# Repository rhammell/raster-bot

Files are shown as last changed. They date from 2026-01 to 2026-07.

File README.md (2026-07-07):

# Raster Bot

Raster Bot

Raster Bot is a compact, two-wheeled differential-drive robot built around an
ESP32 and a capacitive touchscreen display. The project is fully open: it
includes the custom PCB, the 3D-printable mechanical design, the firmware
(packaged as an Arduino library), and the source graphics.

The firmware provides closed-loop motor control with quadrature encoders and
PID speed regulation, battery/charge monitoring, and a touchscreen UI — all
wrapped in a simple high-level API so sketches can drive the bot in a few lines.

## Build guide

A full step-by-step build tutorial — bill of materials, wiring, assembly, and
flashing — is published on Hackster.io:

**[Raster Bot build guide on Hackster.io](https://www.hackster.io/)** <!-- TODO: replace with the real tutorial URL -->

This README focuses on the contents of the repository and the firmware API;
see the Hackster guide if you want to build one from scratch.

## Repository structure

| Folder | Description |
| --- | --- |
| [`firmware/`](firmware/) | ESP32 firmware, packaged as the `Raster_Bot` Arduino library, plus example and tuning sketches. |
| [`hardware/`](hardware/) | KiCad project for the custom PCB (schematic, board layout, and footprint/symbol libraries). |
| [`mechanical/`](mechanical/) | FreeCAD model of the chassis and mechanical parts. |
| [`graphics/`](graphics/) | Logo artwork — SVG source and exported PNGs used for the board silkscreen and the boot splash screen. |

### `firmware/`

The firmware lives in `firmware/Raster_Bot/`, structured as an Arduino library:

| Path | Description |
| --- | --- |
| `src/Raster_Bot.h` / `.cpp` | Top-level `Raster_Bot` class that ties the subsystems together. |
| `src/definitions/` | Compile-time configuration: `pin_definitions.h` (wiring) and `robot_definitions.h` (tuning/behavior). |
| `src/display/` | `Raster_Display` — TFT, capacitive touch, and backlight control (plus the splash logo). |
| `src/battery/` | `Raster_Battery` — battery voltage and charger-status monitoring. |
| `src/drive/` | Differential drive stack: `Raster_Motor`, `Raster_Encoder`, `Raster_PID`, `Raster_Motor_Controller`, and `Raster_Drive`. |
| `examples/` | Standalone feature demos: `BatteryTest`, `GraphicsTest`, `TouchTest`. |
| `tuning/` | Calibration sketches, numbered in the order they should be run: `1_FeedforwardTuning`, `2_PIDTuning`, `3_WheelSyncTuning`, `4_DistanceTuning`. |
| `tests/` | Post-build verification sketches: `ForwardTest`, `DriftTest`. |
| `library.properties` | Arduino library metadata and dependencies. |

**Dependencies** (install via the Arduino Library Manager): Adafruit GFX
Library, Adafruit ILI9341, Adafruit FT6206 Library. Target architecture is
`esp32`.

### `hardware/`

KiCad design for the Raster Bot PCB. Open `hardware/Raster_Bot/Raster_Bot.kicad_pro`
in KiCad to view the schematic and board. Project-local footprint, symbol, and
3D-model libraries are under `hardware/Raster_Bot/libraries/`.

### `mechanical/`

FreeCAD source (`mechanical/src/Raster_Bot.FCStd`) for the robot's mechanical
design, parameterized for resizing.

### `graphics/`

- `src/raster_logo.svg` — master logo artwork.
- `export/raster_logo_silkscreen.png` — logo for the PCB silkscreen.
- `export/raster_logo_splash.png` — logo shown on the display at boot.

## Firmware API

Include the library and create a single `Raster_Bot` instance. It exposes three
subsystems as public members: `display`, `battery`, and `drive`.

```cpp
#include <Raster_Bot.h>

Raster_Bot bot;

void setup() {
    Serial.begin(115200);
    if (!bot.begin()) {
        Serial.println("Raster Bot init failed");
        while (1);
    }
    bot.drive.straight(10.0f);   // drive forward at 10 cm/s
}

void loop() {
    bot.drive.update();          // must be called frequently for PID control
}
```

### `Raster_Bot`

| Method | Description |
| --- | --- |
| `bool begin()` | Initializes the display, battery monitor, and drive subsystems. Returns `false` if any fail. |
| `display` | `Raster_Display` instance (see below). |
| `battery` | `Raster_Battery` instance (see below). |
| `drive` | `Raster_Drive` instance (see below). |

### `Raster_Display`

Extends Adafruit's `Adafruit_ILI9341`, so all standard Adafruit GFX drawing
calls are available in addition to:

| Method | Description |
| --- | --- |
| `bool begin()` | Initializes the TFT, touchscreen, and backlight. |
| `void showSplash()` | Plays the boot splash animation. |
| `void setBrightness(uint8_t brightness)` | Sets backlight brightness (0–255). |
| `bool touched()` | Returns `true` while the screen is being touched. |
| `TS_Point getTouchPoint()` | Returns the current touch point, mapped to the active screen rotation. |

### `Raster_Battery`

| Method | Description |
| --- | --- |
| `void begin()` | Initializes battery/charge-status monitoring. |
| `float voltage()` | Battery voltage in volts. |
| `bool charging()` | `true` while actively charging. |
| `bool chargerConnected()` | `true` when a charging source is plugged in. |

### `Raster_Drive`

Differential drive with per-wheel PID speed control. Call `update()` frequently
from `loop()` to run the control loop.

| Method | Description |
| --- | --- |
| `bool begin()` | Initializes the motor driver, both motor controllers, and encoders. |
| `void straight(float speed_cm_s)` | Drives both wheels at the given speed (negative = reverse). |
| `void stop()` | Stops both motors and goes idle. |
| `void update()` | Runs the drive control loop; call as often as possible. |
| `bool isMoving()` | `true` while a drive command is active. |
| `DriveTelemetry getTelemetry()` | Returns current motor telemetry. |
| `float getDistance()` | Returns cumulative straight-line distance, in cm, driven since power-on. |
| `void resetDistance()` | Resets the cumulative drive distance to zero. |

`DriveTelemetry` contains: `leftRPM`, `leftPWM`, `rightRPM`, `rightPWM`,
`leftCount`, and `rightCount` (wheel-output RPM and raw encoder counts).

## License

<!-- TODO: add a license (e.g. MIT for firmware, CERN-OHL or CC-BY-SA for hardware). -->

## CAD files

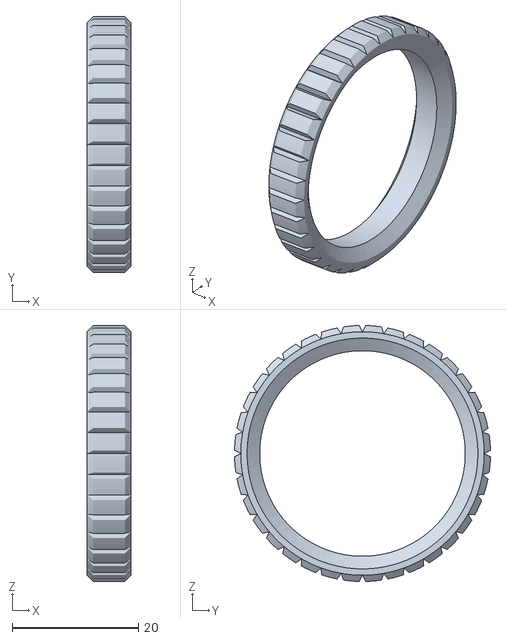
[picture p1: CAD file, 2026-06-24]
mechanical/export/Raster_Bot-Tire.stl
7.00 x 40.5 x 40.5

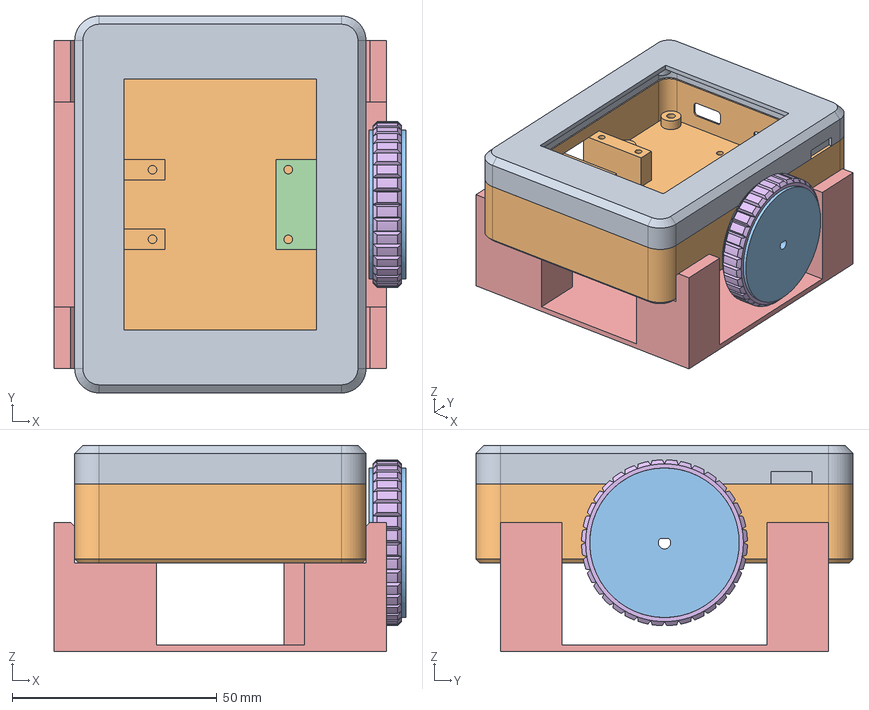
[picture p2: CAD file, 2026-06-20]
mechanical/src/Raster_Bot.FCStd
85.9 x 92.1 x 50.4 mm
Enclosure_Lid
Enclosure_Base
Wheel
Motor_Cover
Test_Stand
Tire

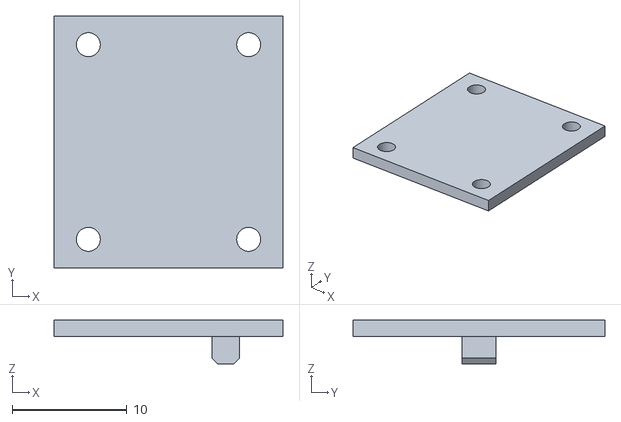
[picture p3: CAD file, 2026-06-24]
mechanical/export/Raster_Bot-Motor_Cover.stl
20.0 x 22.0 x 3.80

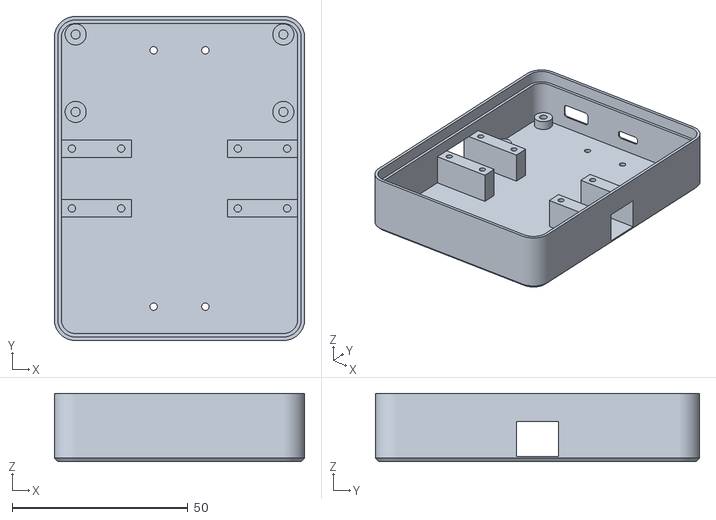
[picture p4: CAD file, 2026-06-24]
mechanical/export/Raster_Bot-Enclosure_Base.stl
71.2 x 92.0 x 19.4

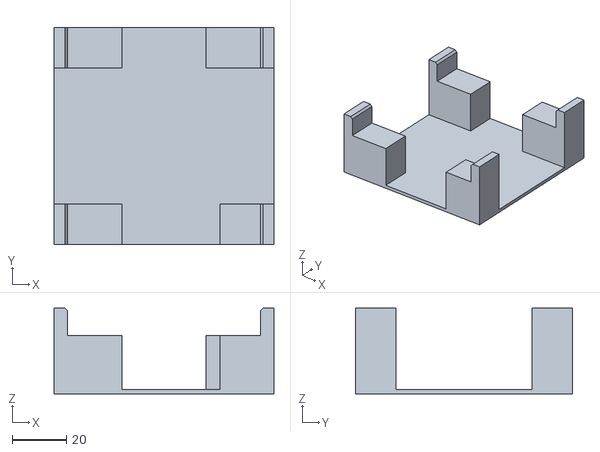
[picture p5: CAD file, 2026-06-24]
mechanical/export/Raster_Bot-Test_Stand.stl
81.2 x 80.0 x 31.6

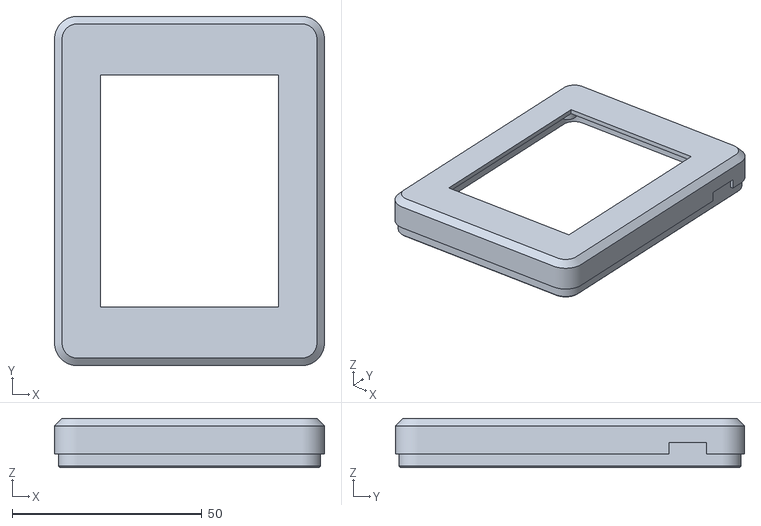
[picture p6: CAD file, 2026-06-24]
mechanical/export/Raster_Bot-Enclosure_Lid.stl
71.2 x 92.0 x 13.0

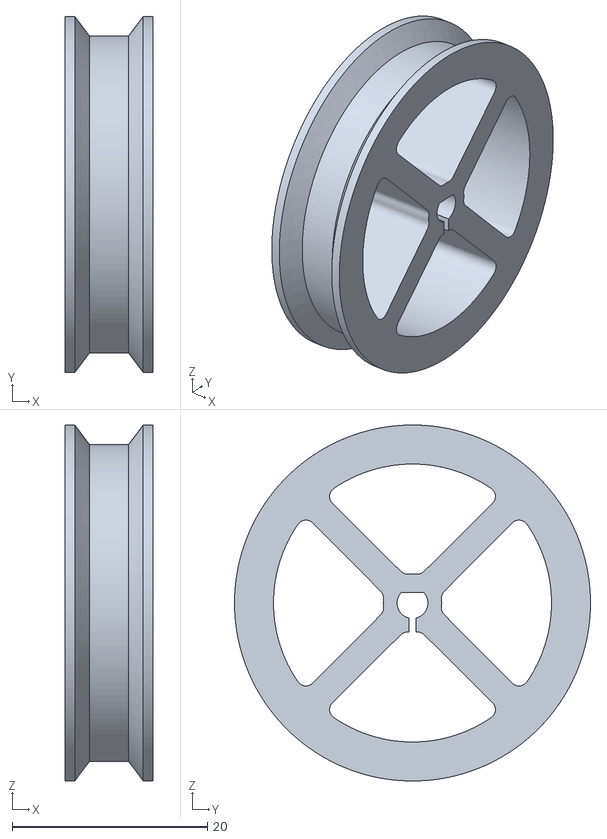
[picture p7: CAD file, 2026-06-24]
mechanical/export/Raster_Bot-Wheel.stl
9.00 x 36.5 x 36.5

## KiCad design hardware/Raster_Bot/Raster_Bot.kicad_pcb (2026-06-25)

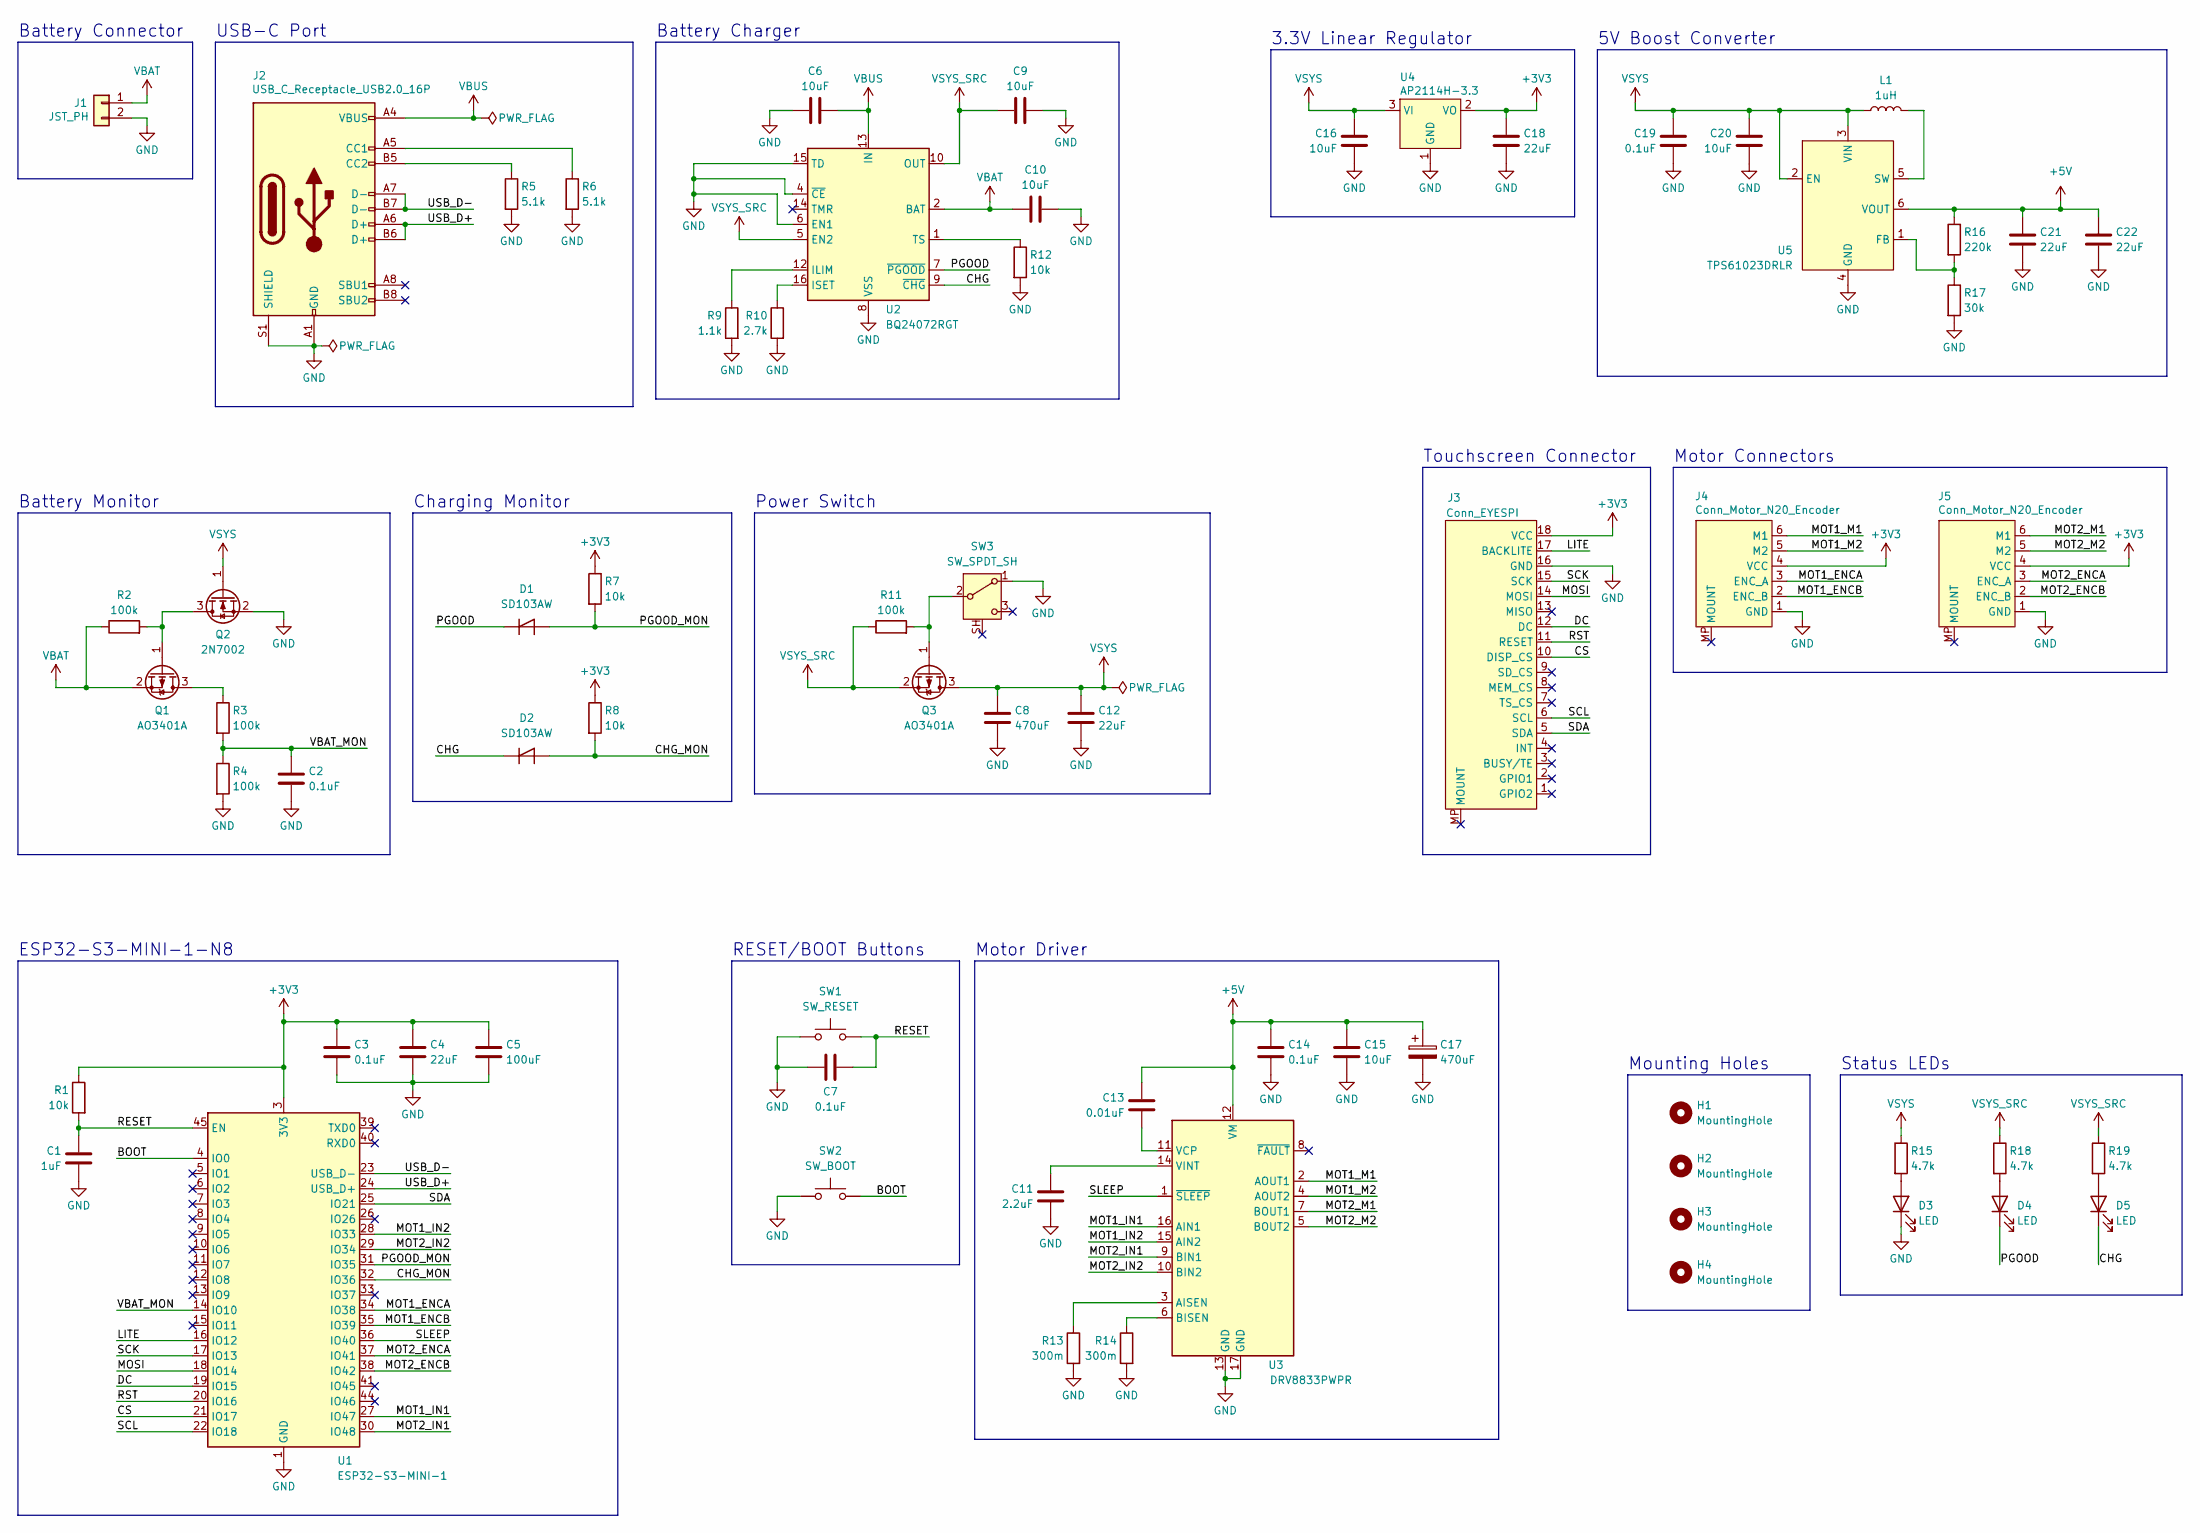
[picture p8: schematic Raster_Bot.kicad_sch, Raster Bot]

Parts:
C1: 1uF; C_0603_1608Metric; LCSC C15849
C2, C3, C7, C14, C19: 0.1uF; C_0603_1608Metric; LCSC C14663
C4, C12, C18, C21, C22: 22uF; C_0805_2012Metric; LCSC C45783
C5: 100uF; C_1206_3216Metric; LCSC C15008
C6, C9, C10, C15, C16, C20: 10uF; C_0805_2012Metric; LCSC C15850
C8, C17: 470uF; CP_Elec_6.3x7.7; LCSC C344072
C11: 2.2uF; C_0603_1608Metric; LCSC C23630
C13: 0.01uF; C_0603_1608Metric; LCSC C57112
D1, D2: SD103AW; D_SOD-123; LCSC C7502706
D3: LED; LED_0805_2012Metric; LCSC C2297
D4, D5: LED; LED_0805_2012Metric; LCSC C2296
H1, H2, H3, H4: MountingHole; MountingHole_2.7mm_M2.5
J1: JST_PH; JST_PH_B2B-PH-K_1x02_P2.00mm_Vertical; LCSC C131337
J2: USB_C_Receptacle_USB2.0_16P; USB_C_Receptacle_G-Switch_GT-USB-7010ASV; LCSC C2988369
J3: Conn_EYESPI; XUNPU_FPC-05F-18PH20_1x18-1MP_P0.5mm_Horizontal; LCSC C2856802
J4, J5: Conn_Motor_N20_Encoder; JST_SH_BM06B-SRSS-TB_1x06-1MP_P1.00mm_Vertical; LCSC C495540
L1: 1uH; L_Coilcraft_XxL4030; LCSC C5441341
Q1, Q3: AO3401A; SOT-23; LCSC C15127
Q2: 2N7002; SOT-23; LCSC C8545
R1, R7, R8, R12: 10k; R_0603_1608Metric; LCSC C25804
R2, R3, R4, R11: 100k; R_0603_1608Metric; LCSC C25803
R5, R6: 5.1k; R_0603_1608Metric; LCSC C23186
R9: 1.1k; R_0603_1608Metric; LCSC C22764
R10: 2.7k; R_0603_1608Metric; LCSC C13167
R13, R14: 300m; R_1206_3216Metric; LCSC C22464904
R15, R18, R19: 4.7k; R_0603_1608Metric; LCSC C23162
R16: 220k; R_0603_1608Metric; LCSC C22961
R17: 30k; R_0603_1608Metric; LCSC C22984
SW1: SW_RESET; SW_SPST_TS-1088-xR020; LCSC C720477
SW2: SW_BOOT; SW_SPST_TS-1088-xR020; LCSC C720477
SW3: SW_SPDT_SH; SW_SPDT_Shouhan_MSK12C02; LCSC C431541
U1: ESP32-S3-MINI-1; LCSC C2913206
U2: BQ24072RGT; VQFN-16-1EP_3x3mm_P0.5mm_EP1.6x1.6mm_ThermalVias; LCSC C140288
U3: DRV8833PWPR; HTSSOP-16-1EP_4.4x5mm_P0.65mm_EP3.4x5mm_Mask2.66x2.46mm_The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; LCSC C50506
U4: AP2114H-3.3; SOT-223-3_TabPin2; LCSC C150716
U5: TPS61023DRLR; SOT-563; LCSC C919459

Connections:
+3V3: C3.1, C4.1, C5.1, C18.1, J3.18 (VCC), J4.4 (VCC), J5.4 (VCC), R1.1, R7.1, R8.1, U1.3 (3V3), U4.2 (VO)
+5V: C13.1, C14.1, C15.1, C17.1, C21.1, C22.1, R16.1, U3.12 (VM), U5.6 (VOUT)
/BOOT: SW2.2, U1.4 (IO0)
/CHG: D2.1 (K), D5.1 (K), U2.9 (~CHG)
/CHG_MON: D2.2 (A), R8.2, U1.32 (IO36)
/CS: J3.10 (DISP_CS), U1.21 (IO17)
/DC: J3.12 (DC), U1.19 (IO15)
/LITE: J3.17 (BACKLITE), U1.16 (IO12)
/MOSI: J3.14 (MOSI), U1.18 (IO14)
/MOT1_ENCA: J4.3 (ENC_A), U1.34 (IO38)
/MOT1_ENCB: J4.2 (ENC_B), U1.35 (IO39)
/MOT1_IN1: U1.27 (IO47), U3.16 (AIN1)
/MOT1_IN2: U1.28 (IO33), U3.15 (AIN2)
/MOT1_M1: J4.6 (M1), U3.2 (AOUT1)
/MOT1_M2: J4.5 (M2), U3.4 (AOUT2)
/MOT2_ENCA: J5.3 (ENC_A), U1.37 (IO41)
/MOT2_ENCB: J5.2 (ENC_B), U1.38 (IO42)
/MOT2_IN1: U1.30 (IO48), U3.9 (BIN1)
/MOT2_IN2: U1.29 (IO34), U3.10 (BIN2)
/MOT2_M1: J5.6 (M1), U3.7 (BOUT1)
/MOT2_M2: J5.5 (M2), U3.5 (BOUT2)
/PGOOD: D1.1 (K), D4.1 (K), U2.7 (~PGOOD)
/PGOOD_MON: D1.2 (A), R7.2, U1.31 (IO35)
/RESET: C1.1, C7.1, R1.2, SW1.2, U1.45 (EN)
/RST: J3.11 (RESET), U1.20 (IO16)
/SCK: J3.15 (SCK), U1.17 (IO13)
/SCL: J3.6 (SCL), U1.22 (IO18)
/SDA: J3.5 (SDA), U1.25 (IO21)
/SLEEP: U1.36 (IO40), U3.1 (~SLEEP)
/USB_D+: J2.A6 (D+), J2.B6 (D+), U1.24 (USB_D+)
/USB_D-: J2.A7 (D-), J2.B7 (D-), U1.23 (USB_D-)
/VBAT_MON: C2.1, R3.2, R4.1, U1.14 (IO10)
GND: C1.2, C2.2, C3.2, C4.2, C5.2, C6.1, C7.2, C8.2, C9.2, C10.2, C11.2, C12.2, C14.2, C15.2, C16.2, C17.2, C18.2, C19.2, C20.2, C21.2, C22.2, D3.1 (K), J1.2, J2.A1 (GND), J2.A12 (GND), J2.B1 (GND), J2.B12 (GND), J2.S1 (SHIELD), J3.16 (GND), J4.1 (GND), J5.1 (GND), Q2.2 (S), R4.2, R5.2, R6.2, R9.2, R10.2, R12.2, R13.2, R14.2, R17.2, SW1.1, SW2.1, SW3.1 (A), U1.1 (GND), U1.2 (GND), U1.42 (GND), U1.43 (GND), U1.46 (GND), U1.47 (GND), U1.48 (GND), U1.49 (GND), U1.50 (GND), U1.51 (GND), U1.52 (GND), U1.53 (GND), U1.54 (GND), U1.55 (GND), U1.56 (GND), U1.57 (GND), U1.58 (GND), U1.59 (GND), U1.60 (GND), U1.61 (GND), U1.62 (GND), U1.63 (GND), U1.64 (GND), U1.65 (GND), U2.4 (~CE), U2.6 (EN1), U2.8 (VSS), U2.15 (TD), U2.17 (VSS), U3.13 (GND), U3.17 (GND), U4.1 (GND), U5.4 (GND)
unnamed: D3.2 (A), R15.2
unnamed: D4.2 (A), R18.2
unnamed: D5.2 (A), R19.2
unnamed: J2.A5 (CC1), R6.1
unnamed: J2.B5 (CC2), R5.1
unnamed: Q1.3 (D), R3.1
unnamed: Q1.1 (G), Q2.3 (D), R2.2
unnamed: Q3.1 (G), R11.2, SW3.2 (B)
unnamed: R9.1, U2.12 (ILIM)
unnamed: R10.1, U2.16 (ISET)
unnamed: R12.1, U2.1 (TS)
unnamed: R13.1, U3.3 (AISEN)
unnamed: R14.1, U3.6 (BISEN)
unnamed: C13.2, U3.11 (VCP)
unnamed: C11.1, U3.14 (VINT)
unnamed: R16.2, R17.1, U5.1 (FB)
unnamed: L1.2, U5.5 (SW)
VBAT: C10.1, J1.1, Q1.2 (S), R2.1, U2.2 (BAT), U2.3 (BAT)
VBUS: C6.2, J2.A4 (VBUS), J2.A9 (VBUS), J2.B4 (VBUS), J2.B9 (VBUS), U2.13 (IN)
VSYS: C8.1, C12.1, C16.1, C19.1, C20.1, L1.1, Q2.1 (G), Q3.3 (D), R15.1, U4.3 (VI), U5.2 (EN), U5.3 (VIN)
VSYS_SRC: C9.1, Q3.2 (S), R11.1, R18.1, R19.1, U2.5 (EN2), U2.10 (OUT), U2.11 (OUT)

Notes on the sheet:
Motor Connectors
ESP32-S3-MINI-1-N8
RESET/BOOT Buttons
Battery Charger
Battery Monitor
Touchscreen Connector
Charging Monitor
5V Boost Converter
Status LEDs
3.3V Linear Regulator
Mounting Holes
USB-C Port
Battery Connector
Power Switch
Motor Driver

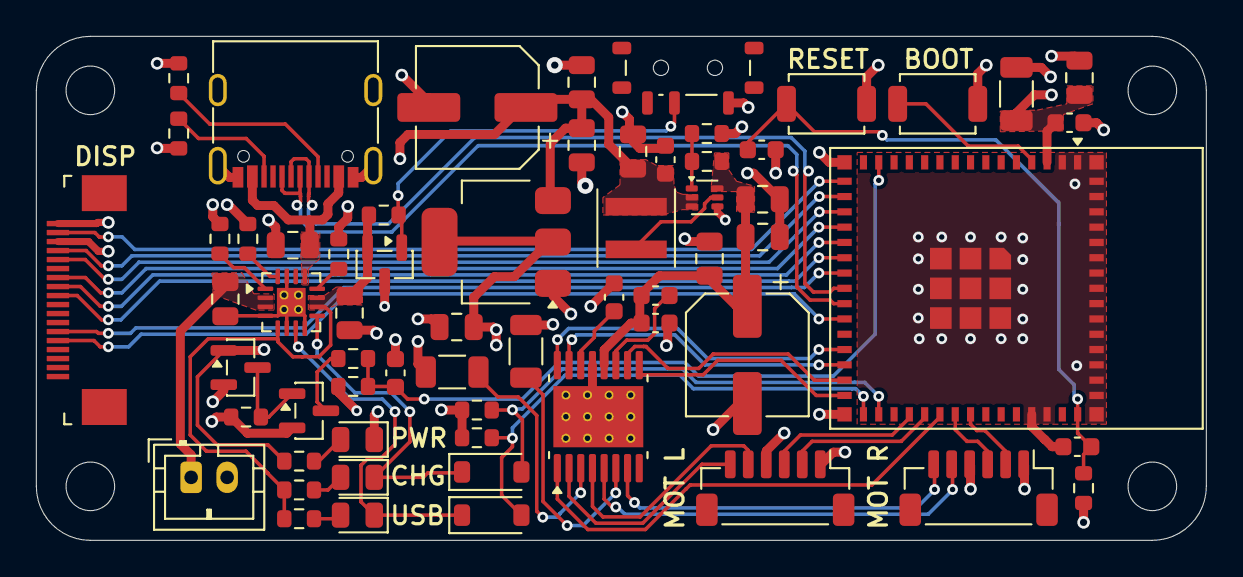
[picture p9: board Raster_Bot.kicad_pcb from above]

Board: 4 copper layers, 65.0 x 28.0 mm, 67 parts (0 on the bottom side), 54 nets.

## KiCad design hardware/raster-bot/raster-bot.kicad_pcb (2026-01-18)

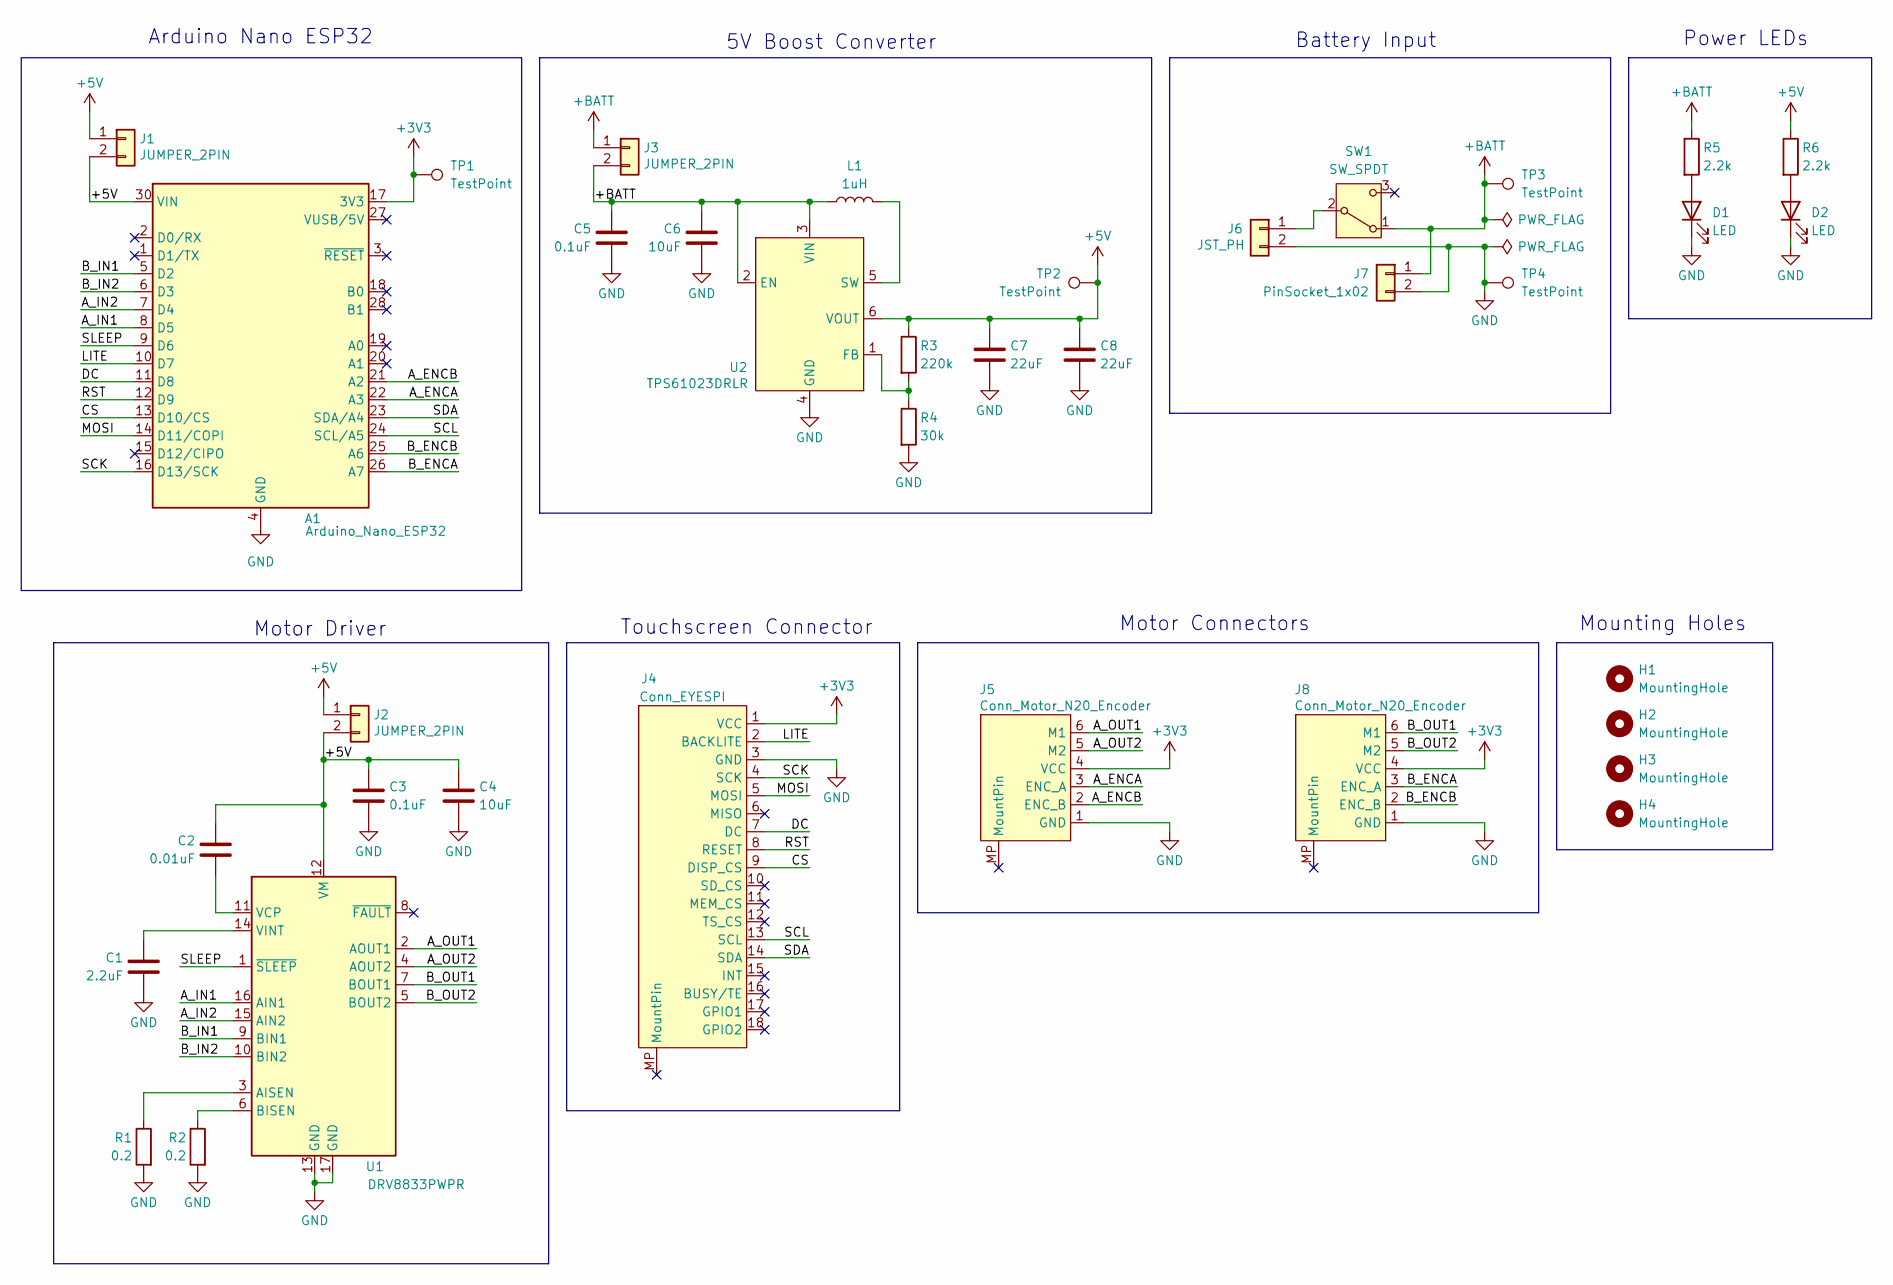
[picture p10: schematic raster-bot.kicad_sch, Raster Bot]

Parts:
A1: Arduino_Nano_ESP32; Arduino_Nano
C1: 2.2uF; C_0805_2012Metric; Voltage 6.3; LCSC C377773
C2: 0.01uF; C_0805_2012Metric; Voltage 16; LCSC C1710
C3, C5: 0.1uF; C_0805_2012Metric; LCSC C28233
C4, C6: 10uF; C_0805_2012Metric; LCSC C15850
C7, C8: 22uF; C_0805_2012Metric; LCSC C45783
D1, D2: LED; LED_0603_1608Metric; LCSC C2286
H1, H2, H3, H4: MountingHole; MountingHole_3.2mm_M3
J1, J2, J3: JUMPER_2PIN; PinHeader_1x02_P2.54mm_Vertical; LCSC C124375
J4: Conn_EYESPI; LCSC C2856802
J5, J8: Conn_Motor_N20_Encoder; LCSC C495540
J6: JST_PH; JST_PH_B2B-PH-K_1x02_P2.00mm_Vertical; LCSC C131337
J7: PinSocket_1x02; PinSocket_1x02_P2.54mm_Vertical
L1: 1uH; L_Coilcraft_XxL4030; LCSC C5441341
R1, R2: 0.2; R_1206_3216Metric; LCSC C7467885
R3: 220k; R_0603_1608Metric; LCSC C22961
R4: 30k; R_0603_1608Metric; LCSC C22984
R5, R6: 2.2k; R_0603_1608Metric; LCSC C4190
SW1: SW_SPDT; SW_SPDT_Shouhan_MSK12C02; LCSC C431541
TP1, TP2, TP3, TP4: TestPoint; TestPoint_Pad_1.5x1.5mm
U1: DRV8833PWPR; HTSSOP-16-1EP_4.4x5mm_P0.65mm_EP3.4x5mm_Mask2.66x2.46mm_The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; LCSC C50506
U2: TPS61023DRLR; SOT-563; LCSC C919459

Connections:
+3V3: A1.17 (3V3), J4.1 (VCC), J5.4 (VCC), J8.4 (VCC), TP1.1
+5V: A1.30 (VIN), C2.1, C3.1, C4.1, C7.1, C8.1, J1.1, J1.2, J2.1, J2.2, R3.1, R6.1, TP2.1, U1.12 (VM), U2.6 (VOUT)
+BATT: C5.1, C6.1, J3.1, J3.2, J7.1, L1.1, R5.1, SW1.1 (A), TP3.1, U2.2 (EN), U2.3 (VIN)
/A_ENCA: A1.22 (A3), J5.3 (ENC_A)
/A_ENCB: A1.21 (A2), J5.2 (ENC_B)
/A_IN1: A1.8 (D5), U1.16 (AIN1)
/A_IN2: A1.7 (D4), U1.15 (AIN2)
/A_OUT1: J5.6 (M1), U1.2 (AOUT1)
/A_OUT2: J5.5 (M2), U1.4 (AOUT2)
/B_ENCA: A1.26 (A7), J8.3 (ENC_A)
/B_ENCB: A1.25 (A6), J8.2 (ENC_B)
/B_IN1: A1.5 (D2), U1.9 (BIN1)
/B_IN2: A1.6 (D3), U1.10 (BIN2)
/B_OUT1: J8.6 (M1), U1.7 (BOUT1)
/B_OUT2: J8.5 (M2), U1.5 (BOUT2)
/CS: A1.13 (D10/CS), J4.9 (DISP_CS)
/DC: A1.11 (D8), J4.7 (DC)
/LITE: A1.10 (D7), J4.2 (BACKLITE)
/MOSI: A1.14 (D11/COPI), J4.5 (MOSI)
/RST: A1.12 (D9), J4.8 (RESET)
/SCK: A1.16 (D13/SCK), J4.4 (SCK)
/SCL: A1.24 (SCL/A5), J4.13 (SCL)
/SDA: A1.23 (SDA/A4), J4.14 (SDA)
/SLEEP: A1.9 (D6), U1.1 (~SLEEP)
GND: A1.4 (GND), A1.29 (GND), C1.2, C3.2, C4.2, C5.2, C6.2, C7.2, C8.2, D1.1 (K), D2.1 (K), J4.3 (GND), J5.1 (GND), J6.2, J7.2, J8.1 (GND), R1.2, R2.2, R4.2, TP4.1, U1.13 (GND), U1.17 (GND), U2.4 (GND)
unnamed: D1.2 (A), R5.2
unnamed: D2.2 (A), R6.2
unnamed: J6.1, SW1.2 (B)
unnamed: R1.1, U1.3 (AISEN)
unnamed: R2.1, U1.6 (BISEN)
unnamed: C2.2, U1.11 (VCP)
unnamed: C1.1, U1.14 (VINT)
unnamed: R3.2, R4.1, U2.1 (FB)
unnamed: L1.2, U2.5 (SW)

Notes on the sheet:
Battery Input
Power LEDs
Motor Connectors
Mounting Holes
Touchscreen Connector
Motor Driver
5V Boost Converter
Arduino Nano ESP32

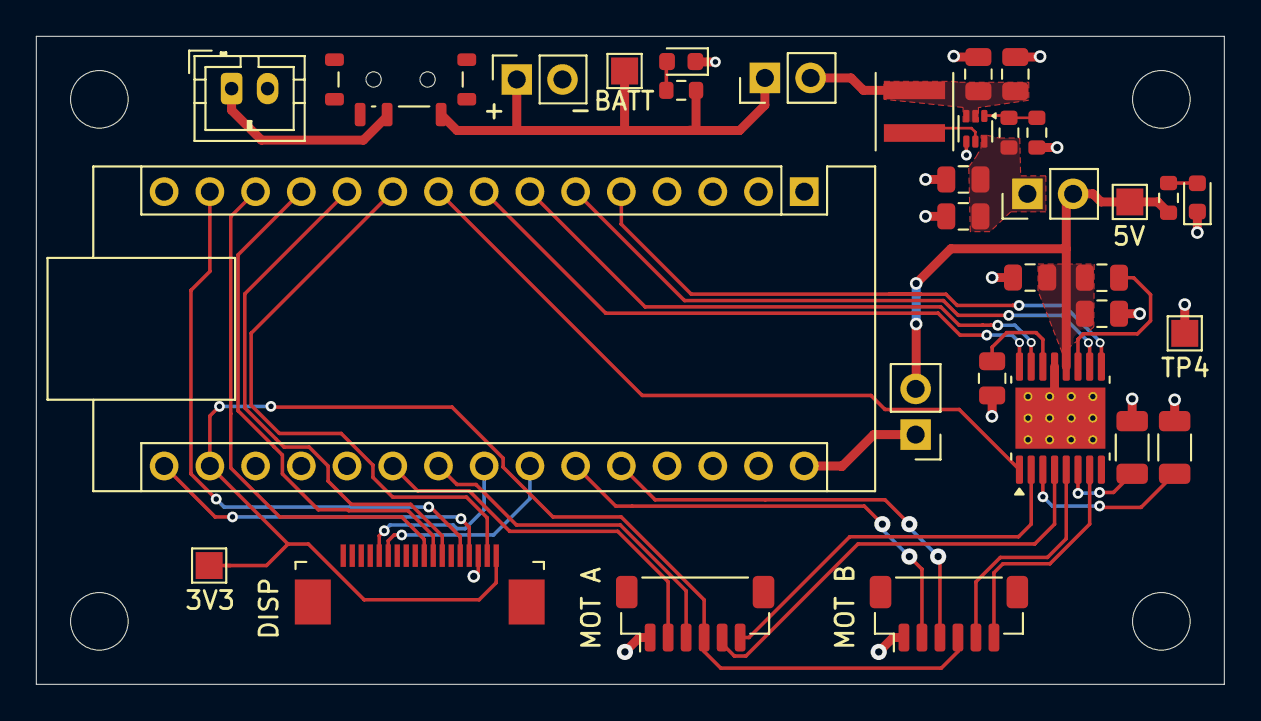
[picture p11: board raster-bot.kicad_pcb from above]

Board: 2 copper layers, 66.0 x 36.0 mm, 37 parts (0 on the bottom side), 34 nets.

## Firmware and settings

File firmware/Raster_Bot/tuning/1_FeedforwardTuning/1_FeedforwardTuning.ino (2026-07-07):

/*
 * 1_FeedforwardTuning - velocity feedforward characterization for Raster_Bot
 *
 * Run this BEFORE PID tuning. It measures your motors' open-loop map of
 * "PWM in -> steady RPM out", which is exactly the data the velocity
 * feedforward table (PID_FF_RPM / PID_FF_PWM in robot_definitions.h) needs.
 * Feedforward is a physical property of the motor + gearbox + wheel + load +
 * battery; it does NOT depend on the PID gains, so it is measured open-loop
 * here with the PID bypassed entirely.
 *
 * What it does:
 *   Steps the raw motor PWM from PWM_START to PWM_MAX in PWM_STEP increments.
 *   It holds each level for DWELL_MS, averages the measured RPM over the final
 *   AVG_MS (once the speed has settled), and logs the result. At the end it
 *   prints a paste-ready PID_FF table.
 *
 * How to use it:
 *   1. Put the bot on the ground (or under representative load) with a
 *      well-charged battery - feedforward is load- and voltage-dependent.
 *   2. Compile, upload, open the Serial Monitor at 115200, and let the full
 *      sweep run without touching the bot. It drives forward the whole time.
 *   3. Copy the printed PID_FF_RPM / PID_FF_PWM / PID_FF_POINTS block into
 *      robot_definitions.h. Thin the points if you like - the table is linearly
 *      interpolated, so ~5-6 well-spaced points across your speed range are
 *      plenty. Add extra points where the curve bends most (usually the top).
 *   4. Set PID_FEEDFORWARD_ENABLE to 1, then move on to 2_PIDTuning.
 *
 * Notes:
 *   - The lowest PWM levels may report ~0 RPM: that is the motor's deadband
 *     (stiction). Levels below MIN_TABLE_RPM are shown in the log but omitted
 *     from the paste-ready table (only the 0,0 anchor represents the low end).
 *   - PWM_MAX defaults to full scale to discover the whole curve. You only need
 *     table points up to the PWM that reaches your top speed (MAX_SPEED_CM_S);
 *     higher rows can be dropped.
 *
 * Screen: 240x320 (Portrait, Rotation 0)
 */

#include <Raster_Bot.h>

// Raster Bot instance
Raster_Bot bot;

// --- Sweep configuration ---
// Raw PWM levels tested: PWM_START, PWM_START+PWM_STEP, ... up to PWM_MAX.
const int      PWM_START = 30;     // first level (near/just below the deadband)
const int      PWM_STEP  = 15;     // increment between levels
const int      PWM_MAX   = 255;    // last level (full scale = whole curve)
const uint32_t DWELL_MS  = 2500;   // time held at each level so speed settles
const uint32_t AVG_MS    = 1000;   // final window of each dwell averaged for RPM
const float    MIN_TABLE_RPM = 2.0f;  // levels slower than this are deadband

// Max number of sweep levels we can store
const int MAX_LEVELS = 64;

// Center a "PWM <value>" readout (size 3) on the 240px-wide display
void printPWM(int pwm, int y) {
    char buf[16];
    snprintf(buf, sizeof(buf), "PWM %d", pwm);
    bot.display.setTextSize(3);
    int w = strlen(buf) * 6 * 3;
    bot.display.setCursor((240 - w) / 2, y);
    bot.display.print(buf);
}

// Center a "<value> RPM" readout (size 3) on the 240px-wide display
void printRPM(float rpm, int y) {
    char buf[16];
    char num[8];
    dtostrf(rpm, 0, 1, num);
    snprintf(buf, sizeof(buf), "%s RPM", num);
    bot.display.setTextSize(3);
    int w = strlen(buf) * 6 * 3;
    bot.display.setCursor((240 - w) / 2, y);
    bot.display.print(buf);
}

// Print the paste-ready PID_FF table from the collected sweep results
void printTable(const int* pwm, const float* rpm, int n) {
    Serial.println();
    Serial.println("===== Feedforward sweep complete =====");
    Serial.println("Paste into robot_definitions.h (thin points as desired):");
    Serial.println();

    // Count usable points (above the deadband) plus the 0,0 anchor
    Serial.print("constexpr float PID_FF_RPM[]   = {0.0f");
    int points = 1;
    for (int i = 0; i < n; i++) {
        if (rpm[i] < MIN_TABLE_RPM) continue;
        Serial.print(", ");
        Serial.print(rpm[i], 1);
        Serial.print("f");
        points++;
    }
    Serial.println("};");

    Serial.print("constexpr float PID_FF_PWM[]   = {0.0f");
    for (int i = 0; i < n; i++) {
        if (rpm[i] < MIN_TABLE_RPM) continue;
        Serial.print(", ");
        Serial.print(pwm[i]);
        Serial.print(".0f");
    }
    Serial.println("};");

    Serial.print("constexpr int   PID_FF_POINTS  = ");
    Serial.print(points);
    Serial.println(";");
    Serial.println();
    Serial.println("Then set PID_FEEDFORWARD_ENABLE to 1 and run 2_PIDTuning.");
}

void setup() {
    // Initialize serial communication
    Serial.begin(115200);
    Serial.println("Raster Bot Feedforward Tuning");

    // Initialize the bot
    if (!bot.begin()) {
        Serial.println("Failed to initialize Raster Bot!");
        while (1);
    }
    Serial.println("Raster Bot initialized successfully");
    Serial.print("Sweeping PWM ");
    Serial.print(PWM_START);
    Serial.print(" to ");
    Serial.print(PWM_MAX);
    Serial.print(" in steps of ");
    Serial.println(PWM_STEP);

    // Draw static TFT layout (240px wide)
    bot.display.fillScreen(ILI9341_BLACK);
    bot.display.setTextColor(ILI9341_CYAN);
    bot.display.setTextSize(2);
    bot.display.setCursor(10, 6);
    bot.display.print("Feedforward");
    bot.display.setTextColor(ILI9341_WHITE);
    bot.display.setTextSize(1);
    bot.display.setCursor(10, 26);
    bot.display.print("Raster Bot");

    // Countdown before driving
    for (int i = 5; i > 0; i--) {
        bot.display.fillRect(0, 304, 240, 16, ILI9341_BLACK);
        bot.display.setTextSize(1);
        bot.display.setTextColor(ILI9341_DARKGREY);
        bot.display.setCursor(4, 308);
        bot.display.print("Sweeping in ");
        bot.display.print(i);
        bot.display.print("...");
        delay(1000);
    }
    bot.display.fillRect(0, 304, 240, 16, ILI9341_BLACK);
}

void loop() {
    // Sweep state
    static int      levelIdx = 0;
    static uint32_t levelStart = 0;
    static uint32_t lastSample = 0;
    static double   lSum = 0, rSum = 0;
    static int      nAvg = 0;
    static bool     done = false;

    // Collected results
    static int   resultPWM[MAX_LEVELS];
    static float resultRPM[MAX_LEVELS];
    static int   nResults = 0;

    // Once finished, hold the motors stopped
    if (done) {
        bot.drive.stop();
        return;
    }

    // Current PWM level under test
    int pwm = PWM_START + levelIdx * PWM_STEP;

    // Drive both wheels open-loop at this PWM (self-rate-limited internally)
    bot.drive.updateOpenLoop(pwm);

    // Start-of-level bookkeeping
    if (levelStart == 0) {
        levelStart = millis();
        lSum = rSum = 0;
        nAvg = 0;
    }

    uint32_t now = millis();
    uint32_t elapsed = now - levelStart;

    // Sample, average and display every 100 ms
    if (now - lastSample >= 100) {
        lastSample = now;
        DriveTelemetry s = bot.drive.getTelemetry();

        // Accumulate only over the settled final window of the dwell
        if (elapsed >= DWELL_MS - AVG_MS) {
            lSum += s.leftRPM;
            rSum += s.rightRPM;
            nAvg++;
        }

        // Live serial row
        Serial.print("PWM ");
        Serial.print(pwm);
        Serial.print("  L RPM: ");
        Serial.print(s.leftRPM, 1);
        Serial.print("  R RPM: ");
        Serial.println(s.rightRPM, 1);

        // Live display
        bot.display.fillRect(0, 120, 240, 30, ILI9341_BLACK);
        bot.display.setTextColor(ILI9341_YELLOW);
        printPWM(pwm, 120);
        bot.display.fillRect(0, 170, 240, 30, ILI9341_BLACK);
        bot.display.setTextColor(ILI9341_GREEN);
        printRPM((s.leftRPM + s.rightRPM) / 2.0f, 170);
    }

    // End of this level: record the averaged steady RPM and advance
    if (elapsed >= DWELL_MS) {
        float lAvg = nAvg ? (float)(lSum / nAvg) : 0.0f;
        float rAvg = nAvg ? (float)(rSum / nAvg) : 0.0f;
        float avg = (lAvg + rAvg) / 2.0f;

        if (nResults < MAX_LEVELS) {
            resultPWM[nResults] = pwm;
            resultRPM[nResults] = avg;
            nResults++;
        }

        Serial.print(">> LEVEL PWM ");
        Serial.print(pwm);
        Serial.print("  ->  L ");
        Serial.print(lAvg, 1);
        Serial.print("  R ");
        Serial.print(rAvg, 1);
        Serial.print("  avg ");
        Serial.print(avg, 1);
        Serial.println(" RPM");

        // Advance to the next level, or finish
        levelIdx++;
        levelStart = 0;
        if (PWM_START + levelIdx * PWM_STEP > PWM_MAX || nResults >= MAX_LEVELS) {
            bot.drive.stop();
            printTable(resultPWM, resultRPM, nResults);
            done = true;
        }
    }
}

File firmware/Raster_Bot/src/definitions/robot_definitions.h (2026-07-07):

/*
 * robot_definitions.h - Robot tuning and behavioral constants
 *
 * Constants defined in this file describe how the robot behaves
 * rather than how it is wired: physical geometry, control gains,
 * calibration factors, and default settings. These values are
 * intrinsic to the robot and its algorithms, and are shared by
 * the subsystems that need them.
 */

#pragma once

#include <math.h>

// Battery voltage divider ratio (Vbat = Vadc * ratio)
#define VBAT_DIV_RATIO      2.0f

// Wheel geometry
#define WHEEL_DIAMETER_CM       4.05
#define WHEEL_CIRCUMFERENCE_CM  (M_PI * WHEEL_DIAMETER_CM)
#define TICKS_PER_CM            (ENCODER_TICKS_PER_REV / WHEEL_CIRCUMFERENCE_CM)

// Drive speed limits
#define MAX_SPEED_CM_S          12.0f

// Wheel-sync correction gain (tuned with tuning/3_WheelSyncTuning). Keeps the
// left/right wheels balanced: matched counts when driving straight, and
// equal-and-opposite counts when spinning in place.
#define WHEEL_SYNC_KP           0.0f

// Acceleration and deceleration (tuned with tuning/4_DistanceTuning)
// MAX_ACCEL_RPM_S limits how fast the commanded RPM slews toward the target.
// Set to 0 to disable ramping (commanded RPM jumps straight to target).
// 250 RPM/s == Alvik's 5 RPM per 20ms control tick.
#define MAX_ACCEL_RPM_S         57.0f
#define DECEL_DISTANCE_CM       3.0f
#define MIN_SPEED_CM_S          0.5f

// Motor gear ratio (150:1 gearmotors)
#define MOTOR_GEAR_RATIO 150.58

// Motor encoder settings
// ENCODER_MODE: 4 for X4 quadrature (both edges, both channels)
//               2 for X2 quadrature (both edges, channel A only)
#define ENCODER_MODE 4
#define ENCODER_PPR 3             // Pulses per revolution (pole pairs on the magnetic disc)
#define ENCODER_TICKS_PER_REV (ENCODER_PPR * ENCODER_MODE * MOTOR_GEAR_RATIO)

// PID speed controller gains (tuned with tuning/2_PIDTuning)
// With feedforward enabled, the feedforward term supplies the bulk of the
// holding PWM, so the integral only has to trim the residual - keep KI low.
#define PID_KP          6.0f
#define PID_KI          4.0f
#define PID_KD          0.0f  

// PID output limits and loop rate
#define PID_OUTPUT_MIN  -255.0f
#define PID_OUTPUT_MAX   255.0f
#define DRIVE_UPDATE_INTERVAL_US  20000  // 20ms = 50Hz

// Velocity feedforward (tuned with tuning/1_FeedforwardTuning)
// Open-loop PWM required to hold a given wheel speed, measured from the
// 1_FeedforwardTuning sweep data. Applied instantly from the target RPM so the
// wheel reaches speed quickly instead of waiting for the integral to wind up;
// the PID then only trims the residual. The curve is convex (PWM rises steeply
// near top speed), so it is stored as a lookup table and linearly interpolated.
// Set PID_FEEDFORWARD_ENABLE to 0 for pure PID (no feedforward).
#define PID_FEEDFORWARD_ENABLE 1

// |RPM| breakpoints (ascending) and the PWM needed to sustain each. Values
// between points are interpolated; magnitudes beyond the ends are clamped. The
// target's sign is applied to the result, and a target of 0 yields 0.
constexpr float PID_FF_RPM[]   = {0.0f, 15.0f, 29.0f, 38.0f, 47.0f, 57.0f};
constexpr float PID_FF_PWM[]   = {0.0f, 42.0f, 55.0f, 66.0f, 86.0f, 120.0f};
constexpr int   PID_FF_POINTS  = 6;

// Measured-RPM smoothing (exponential moving average)
// Higher alpha = less smoothing/lag; lower alpha = more smoothing/lag.
//Changing alpha alters the loop dynamics and requires re-running PID tuning.
#define RPM_FILTER_ALPHA  0.33f  

// Display and touchscreen settings
#define TFT_DEFAULT_ROTATION   0
#define TFT_DEFAULT_BG_COLOR   ILI9341_BLACK
#define TFT_DEFAULT_BRIGHTNESS 255
#define TOUCH_THRESHOLD 40

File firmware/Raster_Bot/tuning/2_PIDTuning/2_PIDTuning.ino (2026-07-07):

/*
 * 2_PIDTuning - PID gain tuning for Raster_Bot library
 *
 * Run this AFTER 1_FeedforwardTuning. The recommended order is: characterize the
 * velocity feedforward first (tuning/1_FeedforwardTuning), enable it, then tune
 * the PID on top of it here. With feedforward supplying the bulk of the holding
 * PWM, the PID only has to trim the small residual, so the gains (especially
 * KI) stay low and the loop is well behaved.
 *
 * Prerequisites before tuning:
 *   - PID_FEEDFORWARD_ENABLE = 1 with a PID_FF table from 1_FeedforwardTuning
 *     (or set it to 0 to tune pure PID with no feedforward).
 *   - WHEEL_SYNC_KP = 0 and MAX_ACCEL_RPM_S = 0 (ramping off), so the PID
 *     responds to a clean step input with no other control loops active.
 *   - Leave RPM_FILTER_ALPHA at its normal value (do NOT zero it) - the RPM
 *     filter is a passive part of the system the PID must be tuned against,
 *     not a competing control loop.
 *
 * Use this sketch to tune the PID speed controller gains (PID_KP,
 * PID_KI, PID_KD) defined in robot_definitions.h. Each change
 * requires recompiling and uploading.
 *
 * The sketch commands a constant speed and prints the measured RPM
 * so you can observe how the controller responds.
 *
 * Output modes (set PLOT_MODE below):
 *   0 = Human-readable Serial Monitor output
 *   1 = Arduino Serial Plotter output (Target, L_RPM, R_RPM)
 *
 * Screen: 240x320 (Portrait, Rotation 0)
 *
 * --- Quick PID Tuning Guide ---
 *
 * 1. Set PID_KI = 0 and start with a small PID_KP (e.g. 2.0) in
 *    robot_definitions.h. Compile, upload, and open Serial Monitor.
 *
 * 2. Watch how the reported RPM approaches the target.
 *    - Too slow to reach target: increase KP.
 *    - Oscillates around target or overshoots: decrease KP.
 *    Repeat until RPM rises quickly without oscillating. A small
 *    steady-state error (offset from target) is expected with KP alone.
 *    (With feedforward enabled the wheel starts near target, so the P
 *    response is small - that is expected.)
 *
 * 3. Add a small PID_KI (e.g. 1.0) to eliminate the steady-state error.
 *    - RPM still settles below target: increase KI.
 *    - RPM overshoots then slowly settles, or oscillates: decrease KI.
 *    With feedforward doing most of the work, KI can stay low - it only
 *    trims the residual the feedforward leaves behind.
 *
 * 4. Good result: RPM reaches and holds the target with no sustained
 *    oscillation and no visible overshoot. Convergence within a few
 *    seconds is acceptable — ramping will eliminate the large step
 *    response in normal operation.
 *
 * 5. Sanity-check the tune at several speeds across your range (set
 *    DRIVE_SPEED_CM_S below), since the motor is nonlinear. When done,
 *    re-enable MAX_ACCEL_RPM_S (see tuning/4_DistanceTuning) for smooth launches.
 */

#include <Raster_Bot.h>

// Raster Bot instance
Raster_Bot bot;

// Drive speed and target RPM
// Clamp to MAX_SPEED_CM_S so the displayed target matches the setpoint
// straight() actually commands (it constrains speed to this limit)
const float DRIVE_SPEED_CM_S = 8.0f;
const float CLAMPED_SPEED_CM_S = constrain(DRIVE_SPEED_CM_S, -MAX_SPEED_CM_S, MAX_SPEED_CM_S);
const float TARGET_RPM = (CLAMPED_SPEED_CM_S * 60.0f) / WHEEL_CIRCUMFERENCE_CM;

// Plot mode
// 0 = Serial Monitor, 1 = Serial Plotter
const int   PLOT_MODE = 0;  

// Center a float value on the 240px-wide display
void printCentered(float value, int decimals, int y, int textSize) {
    char buf[16];
    dtostrf(value, 0, decimals, buf);
    bot.display.setTextSize(textSize);
    int w = strlen(buf) * 6 * textSize;
    bot.display.setCursor((240 - w) / 2, y);
    bot.display.print(buf);
}

// Center a "PWM <value>" readout (size 2) on the 240px-wide display
void printPWM(float pwm, int y) {
    char buf[16];
    snprintf(buf, sizeof(buf), "PWM %d", (int)pwm);
    bot.display.setTextSize(2);
    int w = strlen(buf) * 6 * 2;
    bot.display.setCursor((240 - w) / 2, y);
    bot.display.print(buf);
}

void setup() {
    // Initialize serial communication
    Serial.begin(115200);
    Serial.println("Raster Bot PID Tuning");

    // Initialize the bot
    if (!bot.begin()) {
        Serial.println("Failed to initialize Raster Bot!");
        while (1);
    }
    Serial.println("Raster Bot initialized successfully");

    // Print the target RPM
    Serial.print("Target RPM: ");
    Serial.println(TARGET_RPM, 1);

    // Draw static TFT layout (240px wide)
    bot.display.fillScreen(ILI9341_BLACK);

    // Draw the title text
    bot.display.setTextColor(ILI9341_CYAN);
    bot.display.setTextSize(2);
    bot.display.setCursor(10, 6);
    bot.display.print("PID Tuning");
    bot.display.setTextColor(ILI9341_WHITE);
    bot.display.setTextSize(1);
    bot.display.setCursor(10, 26);
    bot.display.print("Raster Bot");

    // Draw the static labels
    bot.display.setTextColor(ILI9341_DARKGREY);
    bot.display.setTextSize(2);
    bot.display.setCursor(54, 58);
    bot.display.print("Target RPM:");
    bot.display.setCursor(84, 128);
    bot.display.print("L RPM:");
    bot.display.setCursor(84, 214);
    bot.display.print("R RPM:");

    // Show target RPM (static)
    bot.display.setTextColor(ILI9341_WHITE);
    printCentered(TARGET_RPM, 1, 78, 4);

    // Placeholders for RPM and PWM values
    bot.display.setTextColor(ILI9341_DARKGREY);
    bot.display.setTextSize(4);
    bot.display.setCursor(108, 148);
    bot.display.print("-");
    bot.display.setCursor(108, 234);
    bot.display.print("-");

    // Countdown before driving
    for (int i = 5; i > 0; i--) {
        bot.display.fillRect(0, 304, 240, 16, ILI9341_BLACK);
        bot.display.setTextSize(1);
        bot.display.setTextColor(ILI9341_DARKGREY);
        bot.display.setCursor(4, 308);
        bot.display.print("Driving in ");
        bot.display.print(i);
        bot.display.print("...");
        delay(1000);
    }
    bot.display.fillRect(0, 304, 240, 16, ILI9341_BLACK);

    // Drive forward at the target speed
    bot.drive.straight(DRIVE_SPEED_CM_S);
}
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

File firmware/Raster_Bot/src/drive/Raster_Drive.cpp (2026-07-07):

#include "Raster_Drive.h"

// =============================================================================
// Raster_Drive Implementation
// =============================================================================

bool Raster_Drive::begin() {
    // Enable DRV8833 motor driver by pulling nSLEEP high
    Serial.println("[Drive] Enabling DRV8833...");
    pinMode(DRV_SLEEP, OUTPUT);
    digitalWrite(DRV_SLEEP, HIGH);

    // Initialize left motor controller (motor, encoder, PID)
    Serial.println("[Drive] Initializing left motor controller...");
    if (!initController(_leftController,
                        MOT_LEFT_IN1, MOT_LEFT_IN2, MOT_LEFT_FLIP,
                        MOT_LEFT_ENC_A, MOT_LEFT_ENC_B, MOT_LEFT_ENC_FLIP)) {
        Serial.println("[Drive] Left motor controller init FAILED");
        return false;
    }
    Serial.println("[Drive] Left motor controller init OK");

    // Initialize right motor controller (motor, encoder, PID)
    Serial.println("[Drive] Initializing right motor controller...");
    if (!initController(_rightController,
                        MOT_RIGHT_IN1, MOT_RIGHT_IN2, MOT_RIGHT_FLIP,
                        MOT_RIGHT_ENC_A, MOT_RIGHT_ENC_B, MOT_RIGHT_ENC_FLIP)) {
        Serial.println("[Drive] Right motor controller init FAILED");
        return false;
    }
    Serial.println("[Drive] Right motor controller init OK");

    return true;
}

bool Raster_Drive::initController(Raster_Motor_Controller& controller,
                                  uint8_t in1Pin, uint8_t in2Pin, bool motorFlip,
                                  uint8_t encAPin, uint8_t encBPin, bool encFlip) {
    // Config carries only per-side wiring; PID gains and encoder mode are
    // read from robot_definitions.h inside the controller's begin().
    MotorControllerConfig config = {
        in1Pin, in2Pin, motorFlip,
        encAPin, encBPin, encFlip
    };
    return controller.begin(config);
}

void Raster_Drive::straight(float speed_cm_s) {
    // Both wheels drive the same direction (translate)
    startMove(speed_cm_s, DriveMode::Straight);
}

void Raster_Drive::spin(float speed_cm_s) {
    // Wheels drive equal-and-opposite so the robot rotates in place about its
    // center. speed_cm_s is the tangential speed of each wheel; positive
    // spins clockwise (left wheel forward, right wheel backward).
    startMove(speed_cm_s, DriveMode::Spin);
}

void Raster_Drive::startMove(float speed_cm_s, DriveMode mode) {
    // Constrain the speed to the maximum speed
    speed_cm_s = constrain(speed_cm_s, -MAX_SPEED_CM_S, MAX_SPEED_CM_S);

    // Convert the speed to target RPM (signed). For a straight this is the
    // forward wheel speed; for a spin it is each wheel's tangential speed.
    _targetRPM = (speed_cm_s * 60.0f) / WHEEL_CIRCUMFERENCE_CM;

    // If starting from a stop, reset controllers (PID state and encoder
    // counts) so the balance correction starts from zero
    if (_mode == DriveMode::Idle) {
        _leftController.reset();
        _rightController.reset();
        _commandedRPM = 0;
        // Encoder counts were just cleared, so realign the odometry delta
        // trackers. The cumulative distance is intentionally left untouched.
        _lastLeftCount = 0;
        _lastRightCount = 0;
        _lastUpdateTime = micros();
    }

    // Selects the wheel pattern applied in update()
    _mode = mode;
}

void Raster_Drive::stop() {
    // Immediately stop both motors and go idle
    _targetRPM = 0;
    _commandedRPM = 0;
    _mode = DriveMode::Idle;
    _leftController.stop();
    _rightController.stop();
}

void Raster_Drive::update() {
    // Nothing to do while idle
    if (_mode == DriveMode::Idle) return;

    // Get the current time and the elapsed time
    uint32_t now = micros();
    uint32_t elapsed = now - _lastUpdateTime;

    // Skip if the minimum interval hasn't passed
    if (elapsed < DRIVE_UPDATE_INTERVAL_US) return;

    // Update the last update time
    _lastUpdateTime = now;

    // Convert the elapsed time to seconds
    float dt = elapsed / 1e6f;

    // Accumulate odometry from the centerline (average) wheel displacement.
    // Skip spins: their residual doesn't cancel under abs and would drift the
    // total. Always refresh baselines so a spin->straight delta stays correct.
    int64_t leftCount = _leftController.getEncoderCount();
    int64_t rightCount = _rightController.getEncoderCount();
    if (_mode != DriveMode::Spin) {
        float centerTicks = ((leftCount - _lastLeftCount)
                           + (rightCount - _lastRightCount)) / 2.0f;
        _distanceCm += fabsf(centerTicks) / TICKS_PER_CM;
    }
    _lastLeftCount = leftCount;
    _lastRightCount = rightCount;

    // Ramp the commanded RPM toward the target at the acceleration limit.
    // MAX_ACCEL_RPM_S <= 0 disables ramping (snap straight to target).
    float maxDelta = MAX_ACCEL_RPM_S * dt;
    if (maxDelta <= 0.0f) {
        _commandedRPM = _targetRPM;
    } else {
        _commandedRPM += constrain(_targetRPM - _commandedRPM, -maxDelta, maxDelta);
    }

    // Proportional wheel-sync correction, applied on top of the ramped command
    // (not slewed by the ramp). WHEEL_SYNC_KP = 0 disables it. 
    if (_mode == DriveMode::Spin) {
        // Spin: wheels run opposite, so counts should sum to 0 (+ = clockwise).
        float tickError = (float)(leftCount + rightCount);
        float correction = WHEEL_SYNC_KP * tickError;
        _leftController.setRPM(_commandedRPM - correction);
        _rightController.setRPM(-_commandedRPM - correction);
    } else {
        // Straight: wheels run together, so counts should stay matched (diff 0).
        float tickError = (float)(leftCount - rightCount);
        float correction = WHEEL_SYNC_KP * tickError;
        _leftController.setRPM(_commandedRPM - correction);
        _rightController.setRPM(_commandedRPM + correction);
    }

    // Run the PID controllers to compute and apply PWM outputs
    _leftController.update(dt);
    _rightController.update(dt);
}

void Raster_Drive::updateOpenLoop(int pwm) {
    // Rate-limit to the normal control interval so each RPM sample integrates
    // the same encoder window the closed-loop path uses.
    uint32_t now = micros();
    uint32_t elapsed = now - _lastUpdateTime;
    if (elapsed < DRIVE_UPDATE_INTERVAL_US) return;
    _lastUpdateTime = now;

    // Drive both wheels at the same raw PWM, bypassing PID/feedforward/ramp
    float dt = elapsed / 1e6f;
    _leftController.updateOpenLoop(dt, pwm);
    _rightController.updateOpenLoop(dt, pwm);
}

bool Raster_Drive::isMoving() const {
    // Return true if the drive is moving, false otherwise
    return _mode != DriveMode::Idle;
}
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

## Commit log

2026-01-16 Initial commit of v0.1 of hardware PCB design
    [raster-bot.kicad_pcb, raster-bot.kicad_sch]
2026-01-18 PCB v0.2 update - added motor JST connectors; refactored custom footprints
    [raster-bot.kicad_pcb, raster-bot.kicad_sch]
2026-01-28 Refactor filenames to Raster_Bot
    [Raster_Bot.kicad_pcb, Raster_Bot.kicad_sch]
2026-02-11 Update hardware design for Raster Bot: modified schematic to include USB-C receptacle, adjusted component properties, and refined sorting options in the project configuration.
    [Raster_Bot.csv, Raster_Bot.kicad_sch]
2026-02-11 Remove obsolete raster-bot.kicad_pro file, cleaning up the project structure.
2026-03-09 [hardware] v0.3 - design upgrade featuring esp32-s3, battery charger, 3.3V LDO, 5V boost coverter
    [Raster_Bot.csv, Raster_Bot.kicad_pcb, Raster_Bot.kicad_sch]
2026-03-09 [hardware] Add version silkscreen;
    [Raster_Bot.kicad_pcb, Raster_Bot.kicad_sch]
2026-03-10 [firmware] Battery voltage and charge monitoring added; Including new example
2026-03-27 [hardware] v0.4 - 4 layer PCB design with ESP32-S3-MINI
    [Raster_Bot.kicad_pcb, Raster_Bot.kicad_sch]
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2026-04-14 [firmware] Refactor BatteryTest example to improve text display; replace centered text with fixed position rows
    [BatteryTest.ino]
2026-04-17 [firmware] Update config for v0.4 hardware; Initial implementation of drive API, including motor controller, motor, encoder, and PID classes
2026-04-18 [firmware] Refactor drive update logic to use elapsed time and update motor controller to accept time delta
2026-04-28 [hardware] v0.5 - Add motor driver bulk capacitor; Remove test pads and jumpers
    [Raster_Bot.kicad_pcb, Raster_Bot.kicad_sch]
2026-04-29 [hardware] Chage ISEN resistor values, part, and placement
    [Raster_Bot.kicad_pcb, Raster_Bot.kicad_sch]
2026-04-29 [firmware] Add splash screen display on startup
    Add showSplash() method to Raster_Display that shows centered
    "Raster Bot" text for a configurable duration. Add splash call
    to GraphicsTest, TouchTest, and BatteryTest examples. Also add
    serial debug printouts to display initialization for easier
    troubleshooting.
    Made-with: Cursor
2026-05-01 [firmware] Add bitmap logo splash screen with fade in/out
    Replace text-based splash with monochrome bitmap logo drawn from
    splash_logo.h. Add backlight fade in/out using analogWrite PWM
    control. Simplify showSplash() to take no parameters with a
    hardcoded 3-second duration.
    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
    [BatteryTest.ino, GraphicsTest.ino, Raster_Display.cpp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]
2026-05-03 [mechanical] Initial commit of mechanical CAD files
    Add new top-level mechanical directory to house FreeCAD project
    files for the robot enclosure and physical parts.
    [Raster_Bot.FCStd]
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2026-05-16 [hardware] v0.6 - Add silkscreen logo; Reposition footprints; Remove custom USB footprint
    [Raster_Bot.kicad_pcb, Raster_Bot.kicad_sch]
2026-05-17 [mechanical] Init commit of FreeCAD design file
    [Raster_Bot.FCStd]
2026-05-18 [mechanical] Move FreeCAD design file to src directory and delete old location
    [Raster_Bot.FCStd]
2026-05-20 [mechanical] Rough enclosure lid and base
    [Raster_Bot.FCStd]
2026-05-21 [mechanical] Update Raster_Bot.FCStd design file
    [Raster_Bot.FCStd]
2026-05-31 [mechanical] Update Raster_Bot.FCStd design file with new changes
    [Raster_Bot.FCStd]
2026-05-31 [mechanical] Update Raster_Bot.FCStd design file with additional modifications
    [Raster_Bot.FCStd]
2026-06-01 [mechanical] Update Raster_Bot.FCStd design file with latest modifications
    [Raster_Bot.FCStd]
2026-06-02 [mechanical] Update Raster_Bot.FCStd design file with recent changes
    [Raster_Bot.FCStd]
2026-06-03 [mechanical] Refresh Raster_Bot.FCStd design file with updated features
    [Raster_Bot.FCStd]
2026-06-04 [mechanical] Refresh Raster_Bot.FCStd design file with new updates
    [Raster_Bot.FCStd]
2026-06-06 [mechanical] Refresh Raster_Bot.FCStd design file with latest updates
    [Raster_Bot.FCStd]
2026-06-09 [hardware] v0.7 - Added bulk capacitance; PCB layout update
    [Raster_Bot.kicad_pcb, Raster_Bot.kicad_sch]
2026-06-11 [hardware] Update PCB UUIDs for components in Raster_Bot.kicad_pcb
    [Raster_Bot.FCStd, Raster_Bot.kicad_pcb]
2026-06-14 [mechanical] Add test stand model
    [Raster_Bot.FCStd]
2026-06-14 [mechanical] Test stand constraint correction to prevent flipping
    [Raster_Bot.FCStd]
2026-06-14 [firmware] Reorganize library into subdirectories and add tuning tests
    Restructure src/ into battery/, display/, drive/, and definitions/
    subdirectories. Replace flat config.h with pin_definitions.h and
    robot_definitions.h. Add tests/ folder with PID, straightness,
    distance, motor stress, and battery life tuning sketches. Update
    example sketches with consistent display headers and improved layouts.
    [battery_log.csv]
2026-06-14 [firmware] Refactor motor and encoder status retrieval into single getStatus() method; Update all example/test sketches to utilize this
2026-06-16 [firmware] Update PID tuning sketch to clamp drive speed and add PWM display
2026-06-16 [firmware] Restore proportional correction for wheel speed to maintain straight driving; Update motor controller to use private member variables.
    [Raster_Drive.cpp, Raster_Motor_Controller.cpp, Raster_Motor_Controller.h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]
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2026-06-19 [mechanical] Modify wheel with robust parameters for error free resizing
    [Raster_Bot.FCStd]
2026-06-20 [mechanical] Modify test stand constraints for error free resizing
    [Raster_Bot.FCStd]
2026-06-20 [mechanical] Add tire with robust parameters for resizing
    [Raster_Bot.FCStd]
2026-06-20 [mechanical] Update Raster_Bot design to improve resize robustness
    [Raster_Bot.FCStd]
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2026-06-21 [firmware] Remove BatteryLife and MotorStress test files
    [battery_log.csv]
2026-06-24 [mechanical] STL exports of each component of bot housing
    [Raster_Bot-Enclosure_Base.stl, Raster_Bot-Enclosure_Lid.stl, Raster_Bot-Motor_Cover.stl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]
2026-06-25 [mechanical] Update Raster_Bot PCB and project file
    [Raster_Bot.kicad_pcb]
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2026-07-02 [firmware] Replace drive moving/spinning bools with DriveMode enum
    [Raster_Drive.cpp]
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2026-07-02 [firmware] Make motor/encoder/PID primitives config-agnostic
    Inject encoder decoding mode via begin() and drop the encoder's
    robot_definitions dependency. Motor controller now reads the shared
    PID gains and encoder mode from robot_definitions and injects them
    into its primitives, so MotorControllerConfig carries only per-side
    wiring.
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
